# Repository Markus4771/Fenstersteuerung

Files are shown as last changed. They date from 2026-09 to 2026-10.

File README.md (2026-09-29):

# Fenstersteuerung

Modulare ESP32-S3-basierte Fenster-/Rollladensteuerung mit 230-V-Rollladenansteuerung, Reedkontakten, RS485 und zwei ULN2003-Ausgangsgruppen.

## Aktueller Hauptplatinenstand

**v3.3ebs2**

Datei:

`hardware/Hauptplatine/Hauptplatine_v3.3ebs2_library_clean_usb_clearance_150x90.kicad_pcb`

### DRC-Status

Der aktuelle KiCad-DRC ist elektrisch sauber:

- 0 offene Verbindungen
- 0 Kurzschlüsse
- 0 Leiterbahnkreuzungen
- 0 Clearance-Fehler
- 0 Dangling-Tracks
- 0 Silkscreen-Warnungen
- 0 Footprint-Fehler

Es verbleiben nur 30 Bibliothekswarnungen durch angepasste bzw. lokal fehlende Footprint-Bibliotheken.

## Hauptfunktionen

- ESP32-S3 DevKitC-1
- 2 × Finder 40.52, 5-V-Spule, DPDT
- Hardware-Interlock für Rollladen AUF/AB
- Mean Well IRM-20-5
- AMS1117-3.3 mit 22-µF-Ausgangskondensator
- MAX3485 RS485
- 2 × ULN2003A
- 2 × 28BYJ-48-Ausgangsgruppe
- Reedkontakte für Offen/Gekippt
- 230-V-Motoranschluss
- getrennte 230-V- und SELV-Bereiche

## Wichtige Dateien

- PCB: `hardware/Hauptplatine/Hauptplatine_v3.3ebs2_library_clean_usb_clearance_150x90.kicad_pcb`
- DRC-Regeln: `hardware/Hauptplatine/Hauptplatine.kicad_dru`
- 230-V-Prüfung: `hardware/Hauptplatine/230V-SICHERHEITSPRUEFUNG.md`
- BOM: `bom/Hauptplatine_v3.3ebs2_BOM.csv`
- Entwicklungsarchiv: `hardware/Hauptplatine/archive/`
- Historie: `docs/ENTWICKLUNGSHISTORIE.md`
- Übergabe für neuen Chat: `NEUER-CHAT.md`

## Noch vor der Prototypenbestellung

1. BOM gegen tatsächlich bestellte Bauteile prüfen.
2. Gerber- und Drill-Dateien aus KiCad erzeugen.
3. Gerber im Viewer kontrollieren.
4. 230-V-Sicherheitsprüfung final abschließen.
5. Erste Inbetriebnahme zunächst ohne Netzspannung durchführen.

## Sicherheit

Der saubere KiCad-DRC ist keine formale Freigabe für 230-V-Betrieb. Luft-/Kriechstrecken, PE-Führung, Absicherung, Bauteilzulassungen, Gehäuse und Endanwendung müssen separat geprüft werden.

## Update v3.3ebs2

- elektrisch sauberer v3.3ebq2-Stand übernommen
- RS485-Klemme bleibt unten, USB-C frei zugänglich
- alle 17 verwendeten Footprints auf projektlokale Bibliothek `Fenstersteuerung.pretty` umgestellt
- `fp-lib-table` liegt im Hauptplatinen-Ordner
- gegenüber v3.3ebq2 keine Änderungen an Routing, Pads, Vias oder Kupfer
- nächster Schritt: KiCad öffnen, Zonen neu füllen und DRC ausführen

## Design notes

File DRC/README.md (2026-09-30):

# DRC-Berichte

Hier werden die KiCad-Design-Rule-Check-Berichte der jeweiligen Hauptplatinen- und Sensorplatinen-Versionen abgelegt.

Ein sauberer DRC ersetzt nicht die zusätzliche Prüfung der tatsächlichen Netzkonnektivität und der 230-V-Sicherheitsabstände.

## Hauptplatine v3.3ebs2

Aktive PCB-Datei:

`hardware/Hauptplatine/Hauptplatine_v3.3ebs2_library_clean_fixed_150x90.kicad_pcb`

Ergebnis der zuletzt vom Benutzer in KiCad ausgeführten DRC-Läufe:

- 0 unverbundene Pads
- 0 Footprint-Fehler
- keine elektrischen Clearance-Fehler
- keine gemeldeten Verstöße gegen die projektspezifischen 230-V-Regeln
- 30 Warnungen vom Typ `lib_footprint_mismatch`

### Bewertung der 30 Library-Mismatch-Warnungen

Die projektlokale Bibliothek `Fenstersteuerung.pretty` wird von KiCad korrekt gefunden.

Ein exemplarischer Direktvergleich des Sicherungshalters
`Fenstersteuerung:Littelfuse_646_5x20`
mit dem auf der PCB eingebetteten Footprint zeigt:

- gleicher Padabstand: 22,7 mm
- gleiche Padgröße: 2,4 x 2,4 mm
- gleicher Bohrdurchmesser: 1,4 mm
- gleicher Gehäuseumriss
- keine Abweichung der für die Fertigung relevanten Grundgeometrie festgestellt

Die verbleibende Warnung ist daher nach aktuellem Prüfstand als Bibliotheks-/Metadatenabweichung zu behandeln und nicht als elektrischer DRC-Fehler.

Vor Fertigungsfreigabe bleiben dennoch erforderlich:

1. Gerber- und Drill-Daten erzeugen.
2. Gerber visuell gegen die PCB prüfen.
3. reale Kaufteile gegen die Footprints prüfen.
4. 230-V-Sicherheitsprüfung separat abschließen.

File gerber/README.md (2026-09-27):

# Gerber

Fertigungsdaten werden erst abgelegt, wenn Routing, DRC, Konnektivitätsprüfung und die separate Sicherheitsprüfung des 230-V-Bereichs abgeschlossen sind.

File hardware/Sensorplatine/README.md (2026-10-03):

# Sensorplatine

## Status

Aktueller Entwicklungsstand: **v4.0.ac**. Diese Version ist der aktuelle manuell platzierte KiCad-10-Basisstand ohne Leiterbahnen und Vias.

Die Sensorplatine ist als abgesetzte Raumklima- und Anwesenheitssensorplatine für die Fenstersteuerung vorgesehen. Die Reedkontakte für Fenster offen/gekippt bleiben direkt an der Hauptplatine und gehören ausdrücklich **nicht** auf diese Sensorplatine.

## Geplante Messgrößen und Bausteine

| Messgröße | Vorgesehener Baustein | Schnittstelle | Hinweis |
|---|---|---|---|
| Temperatur | BME280 | I²C | gemeinsamer Sensor mit Feuchte und Luftdruck |
| Luftfeuchtigkeit | BME280 | I²C | ±3 % rF typischer Einsatzbereich laut Hersteller |
| Luftdruck | BME280 | I²C | 300…1100 hPa |
| CO₂ | Sensirion SCD41 | I²C | echter CO₂-Sensor, spezifizierter Bereich 400…5000 ppm |
| VOC / Luftqualität | Sensirion SGP40 | I²C | VOC-Index für Lüftungs-/Luftgütelogik |
| Helligkeit | Vishay VEML7700 | I²C | digitaler Umgebungslichtsensor |
| Bewegung / Anwesenheit | modular | GPIO / UART | PIR oder mmWave-Modul; endgültiger Typ noch festzulegen |
| Schallpegel | digitales MEMS-Mikrofon | I²S | z. B. INMP441-Klasse; relative Geräuschpegelmessung, keine normgerechte Schallpegelmessung |

## Architektur

Ziel ist, möglichst viele Sensoren über **I²C** anzubinden. Dadurch benötigen BME280, SCD41, SGP40 und VEML7700 gemeinsam nur SDA und SCL.

Zusätzlich werden benötigt:

- I²S-Leitungen für das digitale MEMS-Mikrofon
- mindestens ein GPIO für einen PIR-Sensor
- optional UART für ein mmWave-Anwesenheitsmodul
- Versorgung 3,3 V und ggf. 5 V
- GND

## Bewegung / Anwesenheit

Die Platine soll so vorbereitet werden, dass entweder:

1. ein einfacher PIR-Bewegungssensor verwendet werden kann, oder
2. ein mmWave-Anwesenheitssensor über einen Steckverbinder angeschlossen werden kann.

mmWave ist besonders interessant, weil damit auch ruhende Personen erkannt werden können. Wegen Baugröße und unterschiedlicher Modulvarianten soll der mmWave-Sensor zunächst nicht fest als SMD-Bauteil auf die Platine gesetzt werden.

## Schallpegel

Die Schallmessung soll mit einem digitalen MEMS-Mikrofon erfolgen.

Ziel:

- relativer Geräuschpegel
- Erkennung von ungewöhnlich hoher Lautstärke
- Verlauf über die Zeit
- mögliche spätere Nutzung für Anwesenheits-/Komfortlogik

Die Platine ist **nicht** als kalibriertes oder normgerechtes Schallpegelmessgerät vorgesehen.

## Mechanik / Layout

Beim späteren PCB-Layout beachten:

- BME280 möglichst weit von Spannungsreglern, ESP32 und anderen Wärmequellen platzieren
- SCD41 mit freiem Luftaustausch montieren
- SGP40 ebenfalls mit gutem Luftaustausch platzieren
- VEML7700 an einer Gehäuseöffnung bzw. lichtdurchlässigen Stelle platzieren
- Mikrofon mit definierter Schallöffnung im Gehäuse
- Sensorbereiche nicht unnötig durch Kupferflächen oder Wärmequellen aufheizen
- Befestigungsbohrungen vorsehen
- Beschriftung der Steckverbinder auf dem Silkscreen

## Noch festzulegen

1. Verbindung zwischen Hauptplatine und Sensorplatine
2. Kabellänge zwischen beiden Platinen
3. Versorgungsspannung(en) der Sensorplatine
4. PIR- und/oder mmWave-Modultyp
5. endgültiger MEMS-Mikrofontyp
6. Gehäuseabmessungen und Position der Luft-/Licht-/Schallöffnungen
7. Schutzbeschaltung für die Verbindung zur Hauptplatine
8. KiCad-Schaltplan und PCB-Version v1.0

## Schaltplanstand v1.0

Aktiver Entwurf:

- `Sensorplatine_v1.0.sch`
- lokale Symbolbibliothek: `Sensorplatine_v1.0-cache.lib`
- Pinbelegung: `PINBELEGUNG_v1.0.csv`
- Schaltplan-Spezifikation: `SCHALTPLAN_v1.0.md`

Der Schaltplan enthält bereits:

- STM32G031K8T6 (LQFP-32)
- AP2112K-3.3
- MAX3485 / RS485
- BME280
- SCD41
- SGP40
- VEML7700
- HLK-LD2450
- I2S-MEMS-Mikrofon als noch zu finalisierender Typ
- 4-poligen Anschluss zur Hauptplatine
- SWD-Programmieranschluss

### Vor PCB-Layout noch final festzulegen

1. konkreter I2S-MEMS-Mikrofontyp und Footprint
2. RS485-TVS-Typ
3. 120-Ohm-Abschluss als Jumper/Lötbrücke
4. endgültiger 4-poliger Steckverbinder
5. Footprint des HLK-LD2450 und Antennen-Keepout
6. mechanische Positionen innerhalb 50 x 50 mm

## PCB-Placement v1.0

Erster mechanischer 50 x 50 mm Placement-Entwurf:

`Sensorplatine_v1.0_placement_50x50.kicad_pcb`

Aktuelle Platzierung:

- HLK-LD2450 entlang der oberen Platinenkante
- definierter Antennen-Keepout an der Oberkante
- SCD41 links mit eigener Luftzone
- BME280 und SGP40 mittig im Sensorbereich
- VEML7700 am rechten Rand
- STM32G031K8T6 zentral unten
- MAX3485 und SM712 nahe RS485-Seite
- AP2112K-3.3 unten rechts
- T5848 nahe Gehäuserand für Schallöffnung
- JST-XH 4-polig unten links
- SWD-Header unten
- zunächst zwei 2.5-mm-Befestigungsbohrungen unten

Dieser Stand ist absichtlich noch nicht geroutet. Vor dem Routing werden Footprints und mechanische Abstände final geprüft.

## Routing-Stand v1.0

Neue Datei:

`Sensorplatine_v1.0_routing_draft_50x50.kicad_pcb`

Bereits elektrisch geroutet:

- 5-V-Eingang vom JST-XH-Stecker zum AP2112K
- 3,3-V-Versorgung vom AP2112K zum STM32 und MAX3485
- GND-Verbindungen im Kernbereich
- RS485 A/B vom Hauptanschluss über SM712 zum MAX3485
- USART-Verbindungen MAX3485 <-> STM32
- DE/RE-Steuerung MAX3485 <-> STM32

Die Sensor-Footprints sind in diesem Stand noch bewusst als Platzhalter markiert. Vor dem Routing von I2C, I2S und LD2450 werden die exakten Hersteller-Landpatterns übernommen und geprüft.

## Maximaler Routing-Stand – v1.0

In `Sensorplatine_v1.0_routing_draft_50x50.kicad_pcb` sind jetzt zusätzlich geroutet:

- I2C SDA/SCL vom STM32 bis in die zentrale Sensorzone
- UART TX/RX vom STM32 bis zur LD2450-Modulschnittstelle
- 5 V und GND bis zur LD2450-Modulschnittstelle
- I2S WS / CK / SD vom STM32 bis zur Mikrofonzone
- SWDIO / SWCLK / NRST / 3V3 / GND bis zum SWD-Header

Damit sind praktisch alle langen bzw. kritischen Leiterbahnstrecken vorgeroutet.

Noch offen bleiben nur die kurzen lokalen Verbindungen direkt an:

- BME280
- SCD41
- SGP40
- VEML7700
- T5848
- endgültiges LD2450-Landpattern

Grund: Für diese Bauteile werden vor einer fertigungstauglichen Version die exakten Hersteller-Landpatterns übernommen. Die derzeitigen Sensorflächen sind ausdrücklich noch Platzhalter.

Der aktuelle Stand ist daher ein **maximal gerouteter mechanisch-elektrischer Entwurf**, aber noch keine freigegebene Fertigungsdatei. Vor Gerber-Erzeugung müssen die finalen Footprints eingesetzt und ein KiCad-DRC durchgeführt werden.

## Versionierung

Ab jetzt wird die Sensorplatine strikt versionsbasiert weiterentwickelt.

Regeln:

- vorhandene Hardwareversionen werden nicht mehr überschrieben
- jede elektrische oder mechanische Änderung erzeugt eine neue Version
- reine Dokumentationskorrekturen können innerhalb derselben Version dokumentiert werden
- DRC-Berichte werden passend zur jeweiligen Version abgelegt
- Gerber-Dateien erhalten immer dieselbe Versionsnummer wie das zugehörige PCB

Aktueller Stand:

- **v1.0** = erster 50 x 50 mm Sensorplatinen-Entwurf mit STM32G031, RS485, LD2450 und vorgerouteten Sensorbussen
- nächste Entwicklungsstufe: **v1.1**

Geplante Dateinamen:

- `Sensorplatine_v1.0_routing_draft_50x50.kicad_pcb` – eingefrorener aktueller Stand
- `Sensorplatine_v1.1_50x50.kicad_pcb` – nächste bearbeitete PCB-Version
- `DRC_v1.0.rpt`, `DRC_v1.1.rpt` usw.
- spätere Gerber: `Sensorplatine_v1.1_Gerber.zip` usw.

## Version v1.2

Datei:

`Sensorplatine_v1.2_50x50.kicad_pcb`

Änderungen gegenüber v1.1:

- 5-V-Versorgung neu geroutet
- GND-Backbone neu aufgebaut
- 3,3-V-Verteilung neu geroutet
- RS485 A/B getrennt geführt
- MAX3485 <-> STM32 neu geroutet
- I2C bis zur Sensorzone geroutet
- LD2450 UART sowie 5 V/GND bis zur Modulschnittstelle geroutet
- I2S bis zur Mikrofonzone geroutet
- SWD neu geroutet
- SWD-Header weiter in die Platinenkontur verschoben

Hinweis:
v1.2 basiert auf der in GitHub gespeicherten v1.1. Lokal in KiCad verschobene Bauteile aus einer nicht hochgeladenen `.kicad_pcb` konnten noch nicht übernommen werden.

## Version 4.0

### v4.0.aa – manuelle Neuplatzierung

Datei:

`Sensorplatine_v4.0.aa_placement_only_50x50.kicad_pcb`

- neue manuelle Bauteilplatzierung
- KiCad-10-Dateiformat
- keine Leiterbahnen
- keine Vias
- dient als saubere mechanische Ausgangsbasis

### v4.0.ab – Routingversuch

Datei:

`Sensorplatine_v4.0.ab_50x50.kicad_pcb`

DRC:

`DRC_v4.0.ab.rpt`

Dieser Stand war ein maximaler 2-Lagen-Routingversuch. Der DRC zeigte zu viele geometrische Konflikte und Kurzschlüsse. **v4.0.ab ist deshalb ausdrücklich nicht für Fertigung oder weitere Entwicklung freigegeben.**

### v4.0.ac – aktueller Basisstand

Datei:

`Sensorplatine_v4.0.ac_50x50.kicad_pcb`

- basiert auf der aktuellen manuellen Bauteilplatzierung
- KiCad 10
- aktuell 0 Leiterbahnsegmente
- aktuell 0 Vias
- neuer Ausgangspunkt für das nächste kontrollierte Routing
- Bauteilpositionen sollen vor dem nächsten Routing nicht automatisch verändert werden

**Aktueller Arbeitsstand: v4.0.ae**

### v4.0.ad – konservatives Kernrouting

Datei:

`Sensorplatine_v4.0.ad_50x50.kicad_pcb`

- basiert auf v4.0.ac
- manuelle Bauteilplatzierung unverändert
- +5 V und GND im Kernbereich geroutet
- RS485_A und RS485_B geroutet
- D1 und U7 im RS485-Pfad berücksichtigt
- +3V3 von U9 zu U7 geroutet
- enge Sensor-, I2C-, I2S- und SWD-Bereiche noch bewusst offen
- vor Weiterentwicklung ist ein neuer KiCad-DRC erforderlich

**Aktueller Arbeitsstand: v4.0.ad**

### v4.0.ae – RS485-only routing

Datei:

`Sensorplatine_v4.0.ae_50x50.kicad_pcb`

- basiert auf der reinen v4.0.aa-Manuellplatzierung
- nur RS485_A und RS485_B geroutet
- D1 und U7 angebunden
- Versorgung, I2C, I2S und SWD bleiben bewusst offen
- Ziel: zuerst einen DRC-sauberen RS485-Kern herstellen

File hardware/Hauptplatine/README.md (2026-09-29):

# Hauptplatine – KiCad-Projektordner

## Wichtig beim Öffnen

Nicht nur die einzelne `.kicad_pcb`-Datei herunterladen.

Für die projektlokale Footprint-Bibliothek müssen diese Dateien/Ordner zusammen bleiben:

- `Hauptplatine_v3.3ebs2_library_clean_fixed_150x90.kicad_pcb`
- `fp-lib-table`
- `Fenstersteuerung.pretty/`
- `Hauptplatine.kicad_dru`

Am einfachsten:

1. komplettes Repository herunterladen/klonen
2. in `hardware/Hauptplatine/` wechseln
3. `Hauptplatine_v3.3ebs2_library_clean_fixed_150x90.kicad_pcb` aus diesem Ordner öffnen

Die `fp-lib-table` verweist auf:

`${KIPRJMOD}/Fenstersteuerung.pretty`

Wenn nur die PCB-Datei separat heruntergeladen wird, kann KiCad die lokale Bibliothek nicht finden und meldet für alle Footprints:

`Die aktuelle Konfiguration enthält die Footprint-Bibliothek "Fenstersteuerung" nicht`

## Aktueller DRC-Stand

DRCebs.rpt vom 2026-09-29:

- 0 unconnected pads
- 0 Footprint errors
- keine elektrischen DRC-Fehler
- 30 reine Library-Warnungen wegen nicht geladener Projektbibliothek

Nach Öffnen aus dem vollständigen Projektordner bitte Zonen neu füllen und DRC erneut ausführen.

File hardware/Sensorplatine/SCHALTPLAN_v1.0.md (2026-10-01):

# Sensorplatine v1.0 – Schaltplan-Spezifikation

## Ziel

50 × 50 mm Sensorplatine für die Fenstersteuerung mit eigenem STM32G031K8T6 und RS485-Anbindung an die Hauptplatine.

Die Reedkontakte bleiben an der Hauptplatine.

## Funktionsblöcke

### 1. Versorgung

Eingang von der Hauptplatine:

- +5V
- GND
- RS485_A
- RS485_B

Versorgung:

- +5V direkt für HLK-LD2450
- +5V auf 3V3 über Regler
- 3V3 für STM32G031K8T6, BME280, SCD41, SGP40, VEML7700, MAX3485 und digitales MEMS-Mikrofon

Vorgesehener Regler:

- AP2112K-3.3, SOT-23-5, 600 mA

Abblockung:

- 10 µF am 5-V-Eingang
- 10 µF am 3V3-Ausgang des Reglers
- 100 nF direkt an jedem IC
- zusätzlich 4.7 µF nahe SCD41 / SGP40

### 2. STM32

U1: STM32G031K8T6

Gehäuse:

- LQFP-32
- 7 × 7 mm
- gut handlötbar

Versorgung:

- VDD/VDDA -> 3V3
- VSS/VSSA -> GND
- 100 nF + 1 µF nahe U1

Reset:

- PF2/NRST
- 10 kΩ Pull-up nach 3V3
- Test-/Programmierzugang über SWD

SWD:

- 3V3
- GND
- SWDIO
- SWCLK
- NRST

### 3. I2C-Sensorbus

Bus:

- PB8 = I2C1_SCL
- PB9 = I2C1_SDA

Pull-ups:

- 4.7 kΩ nach 3V3 auf SDA und SCL

Teilnehmer:

#### U2 – BME280

Messgrößen:

- Temperatur
- Luftfeuchtigkeit
- Luftdruck

Anbindung:

- I2C
- VDD = 3V3
- VDDIO = 3V3
- CSB = 3V3
- SDO = GND für Standard-I2C-Adresse
- 100 nF nahe Sensor

#### U3 – SCD41

Messgröße:

- CO2

Anbindung:

- I2C
- Versorgung 3V3
- lokale Abblockung 100 nF + 4.7 µF

Mechanik:

- freie Luftzufuhr vorsehen
- nicht direkt an Wärmequellen platzieren

#### U4 – SGP40

Messgröße:

- VOC / Luftgüte

Anbindung:

- I2C
- VDD und VDDH gemeinsam an 3V3
- VSS und Center-Pad an GND
- 100 nF + lokale Pufferung

#### U5 – VEML7700

Messgröße:

- Umgebungshelligkeit

Anbindung:

- I2C
- VDD = 3V3
- GND = GND
- 100 nF nahe Sensor

Mechanik:

- am Platinenrand / Gehäusefenster platzieren

### 4. mmWave-Anwesenheit

U6/M1: HLK-LD2450

Versorgung:

- 5V direkt
- GND

UART:

- PA2 = USART2_TX -> RX des LD2450
- PA3 = USART2_RX <- TX des LD2450

Mechanik:

- Modul direkt auf Sensorplatine
- Antennenbereich an Platinenkante
- Keepout vor Antenne
- keine Kupferfläche oder große Bauteile vor der Antenne

### 5. RS485 zur Hauptplatine

U7: MAX3485, SOIC-8

Versorgung:

- VCC = 3V3
- GND = GND
- 100 nF direkt an VCC

UART:

- PB6 = USART1_TX -> DI
- PB7 = USART1_RX <- RO
- PB1 = RS485_DE

Enable:

- DE und /RE gemeinsam an PB1
- 10 kΩ Pull-down auf PB1, damit der Treiber beim Reset deaktiviert bleibt

Bus:

- A -> RS485_A
- B -> RS485_B

Abschluss:

- 120 Ω zwischen A und B
- per 2-poligem Jumper oder Lötbrücke zuschaltbar

Schutz:

- TVS für RS485 A/B vorsehen
- optional Serienwiderstände / Common-Mode-Choke als Bestückungsoption

### 6. Digitales Mikrofon

U8: TDK InvenSense T5848, digitales I2S-MEMS-Mikrofon.

Ziel:

- relativer Schallpegel
- keine normgerechte dB-Messung

I2S:

- PA4 = WS/LRCLK
- PA5 = CK/BCLK
- PA7 = SD

Versorgung:

- 3V3
- GND
- 100 nF nahe Mikrofon

Mechanik:

- Mikrofon an Platinenrand
- definierte Schallöffnung im Gehäuse

### 7. Hauptanschluss

J1: 4-poliger Anschluss Hauptplatine <-> Sensorplatine

1. +5V
2. GND
3. RS485_A
4. RS485_B

Steckertyp wird erst mit Gehäuse und Kabelwahl final festgelegt.

## STM32-Pinplanung

| Pinname | phys. Pin | Funktion |
|---|---:|---|
| PB9 | 1 | I2C SDA |
| PB8 | 28 | I2C SCL |
| PA2 | 9 | LD2450 TX |
| PA3 | 10 | LD2450 RX |
| PA4 | 11 | I2S WS |
| PA5 | 12 | I2S CK |
| PA7 | 14 | I2S SD |
| PB1 | 16 | RS485 DE + /RE |
| PB6 | 32 | RS485 TX |
| PB7 | 27 | RS485 RX |
| PA13 | 24 | SWDIO |
| PA14 | 25 | SWCLK |
| PF2/NRST | 6 | Reset |

Die physikalischen Pin-Nummern wurden gegen das aktuelle ST-Datenblatt für STM32G031KxT im LQFP-32 geprüft. Die Alternate-Functions für USART1, USART2 und I2S1 sind ebenfalls abgeglichen.

## Layoutvorgaben 50 × 50 mm

- LD2450 entlang einer Außenkante
- SCD41 und BME280 möglichst weit weg von Regler, STM32 und LD2450-Wärmequellen
- VEML7700 an einer lichtzugänglichen Außenkante
- MEMS-Mikrofon an einer Gehäuseöffnung
- RS485- und 5-V-Anschluss an einer gemeinsamen Kabelseite
- 4 Befestigungsbohrungen, soweit der verfügbare Raum dies zulässt
- GND-Fläche, aber Antennen-Keepout des LD2450 beachten
- Testpunkte für 5V, 3V3, GND, SDA, SCL, RS485_A, RS485_B, TX/RX

## Noch offen

1. endgültiger Footprint des HLK-LD2450
2. Gehäuse und Öffnungen
3. mechanische Platzierung auf 50 x 50 mm
4. PCB-Routing und DRC

## Festgelegte Bauteile – Update

### U8 – TDK InvenSense T5848
- digitaler I2S-Ausgang
- Bottom-Port-MEMS-Mikrofon
- ca. 3.50 x 2.65 x 0.98 mm
- Status: Production
- benötigt eine Schallöffnung im PCB/Gehäuse
- Hinweis: wegen Bottom-Pads nicht klassisch mit Lötkolben an allen Anschlüssen zugänglich; Reflow/Heißluft empfohlen

### D_RS485 – Littelfuse SM712
- speziell für RS485/RS422-Schutz
- asymmetrische TVS-Auslegung für Busleitungen
- zwischen RS485 A/B und GND gemäß Hersteller-Applikation platzieren
- möglichst nahe am externen Steckverbinder

### J1 – JST XH, 4-polig, 2.50 mm
- Through-Hole-Ausführung
- gut von Hand lötbar
- 3 A bei AWG22 laut JST
- Pinbelegung:
  1. +5V
  2. GND
  3. RS485_A
  4. RS485_B

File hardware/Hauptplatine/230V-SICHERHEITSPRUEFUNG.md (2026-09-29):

# 230-V-Sicherheitsprüfung Hauptplatine

Stand: v3.3ebs2  
Status: Entwicklungs-/Prototypenprüfung, **keine formale Sicherheits- oder Fertigungsfreigabe**

## Aktueller Prüfstand

Aktive PCB-Datei:

`hardware/Hauptplatine/Hauptplatine_v3.3ebs2_library_clean_fixed_150x90.kicad_pcb`

Verwendete Designregeln:

`hardware/Hauptplatine/Hauptplatine.kicad_dru`

Interne Entwicklungsziele:

- mindestens 1,5 mm zwischen unterschiedlichen Netzspannungs-Potentialen
- mindestens 6 mm zwischen Netzspannung und SELV
- mindestens 2,0 mm Leiterbahnbreite für Netzspannungsnetze

## Statisch verifizierte Punkte v3.3ebs2

### Netzspannungs-Leiterbahnbreite

Aus der PCB-Datei wurden 56 Leiterbahnsegmente der folgenden Netze ausgewertet:

- AC_L
- AC_N
- PE
- L_PSU_FUSED
- L_MOTOR
- UP_FEED
- DN_FEED
- MOTOR_UP
- MOTOR_DN

Ergebnis:

- kleinste gefundene Leiterbahnbreite: **2,0 mm**
- Segmente unter 2,0 mm: **0**

Damit wird das interne Entwicklungsziel für die Leiterbahnbreite in der statisch ausgewerteten PCB-Geometrie eingehalten.

### Trennung Netzspannung / SELV

Die Leiterplatte besitzt eine echte Kupfer-Keepout-Zone auf F.Cu und B.Cu:

- x = 71 .. 77 mm
- Breite = **6 mm**
- Tracks verboten
- Vias verboten
- Copper Pour verboten

Statische Auswertung der 56 Netzspannungs-Leiterbahnsegmente:

- Netzspannungs-Tracks, die die Keepout-Zone durchqueren: **0**

### Komponenten-/Footprint-Stand

Folgende zuvor problematische Footprints wurden im aktuellen Stand korrigiert bzw. auf die projektlokale Bibliothek umgestellt:

- Mean Well IRM-20-5
- Finder 40.52
- Littelfuse 646 Sicherungshalter
- ESP32-S3 DevKitC-1 Carrier
- Phoenix MKDS Klemmen
- MOV S14K275
- weitere Standard-Footprints in `Fenstersteuerung.pretty`

## Bereits umgesetzte Schutzmaßnahmen

- 6-mm-Trennzone zwischen 230-V-/Motorbereich und SELV-/Logikbereich
- 2,0-mm-Netzspannungsleiterbahnen
- getrennte Sicherung für Netzteilzweig und Motorzweig
- MOV auf der Netzseite
- galvanisch getrenntes AC/DC-Netzteil
- Relaiskontakte räumlich von den Spulenanschlüssen getrennt
- PE wird als eigenes Netz von J1 zum Motorausgang J5 geführt

## Noch vor Prototypenbestellung erforderlich

1. PCB in KiCad 10 öffnen.
2. Alle Kupferzonen neu füllen.
3. `Hauptplatine.kicad_dru` im Design Rule Editor laden bzw. prüfen.
4. „Check rule syntax“ ausführen.
5. vollständigen KiCad-DRC ausführen.
6. insbesondere alle MAINS-different-net-clearance-Verstöße prüfen.
7. bestätigen, dass zwischen allen unterschiedlichen 230-V-Potentialen mindestens das interne Ziel von 1,5 mm erreicht wird.
8. tatsächliche Kaufteile gegen Footprints prüfen:
   - Littelfuse 646
   - Finder 40.52.9.005.0000
   - Mean Well IRM-20-5
   - Phoenix-Klemmen
   - MOV
9. Gerber- und Drill-Daten visuell prüfen.
10. Erstinbetriebnahme ohne Netzspannung durchführen.
11. Netzspannung erst nach separater elektrischer Sicherheitskontrolle anlegen.

## Normative Einordnung

Die oben verwendeten Abstände sind konservative interne Entwicklungsziele und stellen **keinen Nachweis einer Normkonformität** dar.

Die tatsächlich erforderlichen Luft- und Kriechstrecken hängen unter anderem ab von:

- anzuwendender Produktnorm
- Überspannungskategorie
- Verschmutzungsgrad
- Leiterplatten-Materialgruppe / CTI
- Einsatzhöhe
- Basisisolation oder verstärkter Isolation
- Gehäuse und Berührschutz
- Absicherung und Fehlerfallbetrachtung

Vor einem produktiven Einsatz an 230 V ist deshalb eine separate fachliche Sicherheitsbewertung erforderlich.

## Ergebnis v3.3ebs2

Der aktuelle PCB-Stand ist gegenüber den früheren Revisionen wesentlich bereinigt:

- keine Netzspannungsleiterbahn unter 2,0 mm
- keine Netzspannungsleiterbahn durchquert die 6-mm-SELV-Keepout-Zone
- Routing ist vollständig
- Footprints wurden auf die projektlokale Bibliothek vereinheitlicht

Die **finale Freigabe hängt jetzt vor allem vom vollständigen KiCad-DRC mit den Hochspannungsregeln sowie der Prüfung der realen Kaufteile ab**.

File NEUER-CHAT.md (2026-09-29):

# NEUER-CHAT – Fenstersteuerung

## Repository

`Markus4771/Fenstersteuerung`

## Aktueller Stand

Aktuelle Hauptplatine:

`hardware/Hauptplatine/Hauptplatine_v3.3ebs2_library_clean_usb_clearance_150x90.kicad_pcb`

Status:

- Routing abgeschlossen
- 0 offene Verbindungen
- 0 Kurzschlüsse
- 0 Track-Kreuzungen
- 0 Clearance-Fehler
- 0 Dangling-Tracks
- 0 Silkscreen-Warnungen
- nur noch 30 nicht-elektrische Library-Warnungen

## Wichtige Korrekturen des finalen Standes

- Mean Well IRM-20-5 Footprint und Pinbelegung korrigiert
- Finder 40.52 auf offizielles Pinraster korrigiert
- Littelfuse-646-Sicherungshalter auf 22,7-mm-Raster korrigiert
- AMS1117 mit 22-µF-Ausgangskondensator ergänzt
- ESP32-S3 DevKitC-1 J1-Pinbelegung korrigiert
- 230-V-Abstände verbessert
- GND-Zoneninseln und Silkscreen-Warnungen bereinigt

## Projektstruktur

- `hardware/Hauptplatine/` – aktiver Hauptplatinenstand
- `hardware/Hauptplatine/archive/` – alte PCB-Zwischenstände
- `bom/` – Stückliste
- `gerber/` – spätere Fertigungsdaten
- `docs/ENTWICKLUNGSHISTORIE.md` – ausführliche Entwicklungshistorie
- `DRC/` – DRC-Dokumentation

## Nächste Schritte

1. BOM gegen reale Bauteile prüfen.
2. Gerber und Drill in KiCad erzeugen.
3. Gerber visuell prüfen.
4. 230-V-Sicherheitsprüfung finalisieren.
5. Prototyp bestellen.
6. Erstinbetriebnahme ohne Netzspannung.
7. Danach 5 V / 3,3 V / ESP32 / RS485 / Relais / Stepper prüfen.
8. Netzspannung erst nach separater Sicherheitsprüfung.

## Hinweis

Nicht mit Dateien aus `hardware/Hauptplatine/archive/` weiterarbeiten. Aktive Basis ist ausschließlich **v3.3ebs2**.

## Update v3.3ebs2

- elektrisch sauberer v3.3ebq2-Stand übernommen
- RS485-Klemme bleibt unten, USB-C frei zugänglich
- alle 17 verwendeten Footprints auf projektlokale Bibliothek `Fenstersteuerung.pretty` umgestellt
- `fp-lib-table` liegt im Hauptplatinen-Ordner
- gegenüber v3.3ebq2 keine Änderungen an Routing, Pads, Vias oder Kupfer
- nächster Schritt: KiCad öffnen, Zonen neu füllen und DRC ausführen

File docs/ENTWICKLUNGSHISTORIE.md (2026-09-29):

# Entwicklungshistorie – Fenstersteuerung

Diese Datei enthält die frühere ausführliche Entwicklungsdokumentation aus `NEUER-CHAT.md`.

> Hinweis: Für den aktuellen Projektstand bitte `README.md` und `NEUER-CHAT.md` im Repository-Stamm verwenden.

---

# NEUER-CHAT – Fenstersteuerung

## Projekt

GitHub:
https://github.com/Markus4771/Fenstersteuerung

## Ziel

Kompakte ESP32-basierte Fenster-/Rollladensteuerung.

Die Hauptelektronik sitzt im Rollladenkasten. Die Sensorik wird abgesetzt. Das System soll bewusst mehr können als ein einfacher Rollladenaktor:

- Rollladen AUF/AB
- Fenster offen/gekippt erkennen
- Präsenz erkennen
- Raumklima erfassen
- Endlagen-/Hilfsmechanik ansteuern
- Sensorplatine per RS485 anbinden

Es ist **kein Fensterantrieb** vorgesehen.

## Festgelegte Hardware

### Hauptplatine

- ESP32-S3
- 2 x Finder 40.52
- 5-V-Spulen
- DPDT
- Hardware-Interlock
- 230-V-Rollladenmotor-Ausgänge
- 2 x ULN2003
- TOP/BOTTOM-Ausgangsgruppen
- 28BYJ-48 + ULN2003 für Endlagen-/Verstellmechanik
- Reed-Eingänge
- RS485
- ca. 150 x 90 mm
- 2-lagig

### Sensorplatine

- ESP32-C3
- RS485
- 4 Adern zur Hauptplatine:
  - 5 V
  - GND
  - A
  - B
- 3,3-V-kompatibler RS485-Transceiver, z. B. MAX3485
- LD2450 fest eingeplant
- SHT40
- SCD41 optional
- MQ-2 optional

### Reedkontakte

Zwei kabelgebundene Reedkontakte:

1. Fenster offen
2. Fenster gekippt

Die Reedkontakte werden per Kabel direkt von der Hauptelektronik herausgeführt.

## Stromversorgung

Festgelegt:

- 230 V AC Eingang
- Mean Well IRM-20-5
- 5 V / 4 A
- 5-V-Bus
- separate 3,3-V-Regelung
- klare Trennung zwischen Netzspannung und SELV

## Aktuelle PCB-Version

Aktuell:

**Hauptplatine_v3.3al_logic_minimal_150x90.kicad_pcb**

Repository-Pfad:

`hardware/Hauptplatine/Hauptplatine_v3.3al_logic_minimal_150x90.kicad_pcb`

Wichtig:

- v3.3h ist noch nicht vollständig geroutet
- keine Fertigungsfreigabe
- v3.3g basiert auf v3.3f; v3.3f basiert wiederum auf dem sauberen v3.3c-Stand
- v3.3d/v3.3e wegen Routing-Konflikten nicht weiterverwenden
- RS485_A/B weiterhin bewusst offen
- TOP_COIL_1–4 sind aus v3.3f übernommen
- BOT_COIL_1–4 wurden in v3.3g neu geroutet
- BOT_COIL_1 liegt bewusst auf B.Cu, BOT_COIL_2–4 auf F.Cu, um Kreuzungen zu vermeiden

## Noch offene Netze

- TOP_COIL_1–4: DRC prüfen
- BOT_COIL_1–4: neu in v3.3g, DRC prüfen
- STEP_TOP_1–4
- STEP_BOT_1–4
- ROLL_UP
- ROLL_DN
- K1_COIL_LOW
- K2_COIL_LOW
- RS485_A
- RS485_B
- REED_OPEN final prüfen
- REED_TILT final routen/prüfen
- +5 V final prüfen
- GND final prüfen

## Routing-Regel aus den bisherigen Versuchen

Nicht mehrere Netzgruppen gleichzeitig automatisch routen.

Empfohlene Reihenfolge:

1. TOP_COIL
2. BOT_COIL
3. STEP_TOP/BOT
4. Relaisansteuerung
5. RS485
6. Reed-Eingänge
7. Versorgung/GND
8. komplette physische Konnektivitätsprüfung
9. finaler DRC

## Wichtige Lektion aus DRC 3.3c

Ein DRC mit "0 unconnected pads" darf **nicht** automatisch als vollständiges Routing interpretiert werden.

Zusätzlich immer direkt in der PCB-Datei prüfen:

- ob jedes verwendete Netz Leiterbahnsegmente besitzt
- ob alle Pads tatsächlich elektrisch verbunden sind
- ob keine Ratsnest-Verbindungen offen sind

## Fertigungsfreigabe

Nur wenn:

- alle verwendeten Pads physisch verbunden sind
- keine Kurzschlüsse vorhanden sind
- keine Leiterbahnkreuzungen vorhanden sind
- keine offenen/dangling Tracks vorhanden sind
- DRC sauber ist
- RS485 korrekt geroutet ist
- Netzspannungsbereich separat sicherheitstechnisch geprüft ist
- Gerberdaten visuell geprüft sind

## 230-V-Bereich

Vor Produktion separat prüfen:

- Luftstrecken
- Kriechstrecken
- Absicherung
- Leiterbahnbreiten
- Abstand zu 5 V / 3,3 V / GND
- Relaiskontaktführung
- Motoranschlüsse
- Schutzmaßnahmen

Der 230-V-Bereich darf nicht allein aufgrund eines sauberen DRC freigegeben werden.

## Update v3.3h

DRC v3.3g:
- 63 DRC-Verstöße
- 54 offene Verbindungen
- keine gemeldeten Kurzschluss- oder Leiterbahnkreuzungs-Kategorien
- TOP/BOT-Coil-Leitungen hatten offene Enden, weil die Startpunkte nicht auf den tatsächlichen U4/U5-Pads lagen

v3.3h:
- alle bisherigen TOP_COIL_1–4- und BOT_COIL_1–4-Tracks entfernt
- acht Coil-Netze neu direkt von U4/U5 zu J6/J7 geroutet
- tatsächliche Padkoordinaten aus dem DRC/Board verwendet
- nächster Schritt: DRC v3.3h prüfen, erst danach STEP_TOP/STEP_BOT routen

## Update v3.3i

Grund:
- DRC v3.3h zeigte erneut Pad-Kollisionen/Kreuzungen durch direkte diagonale Coil-Leitungen über U4/U5.

Änderungen:
- alle TOP_COIL_1–4- und BOT_COIL_1–4-Tracks aus v3.3h entfernt
- neue Routingstrategie: zuerst horizontal rechts aus U4/U5 herausfächern
- TOP_COIL_1/2 und BOT_COIL_1/2 auf F.Cu
- TOP_COIL_3/4 und BOT_COIL_3/4 mit gezielten Vias auf B.Cu
- keine direkte Diagonalführung mehr durch den DIP-Padbereich
- nächster Schritt: DRC v3.3i prüfen

## Update v3.3j

Wichtige Korrektur:
- Die bisherigen U4/U5-Padkoordinaten waren bei den Routingversuchen falsch transformiert.
- U4/U5 sind im PCB um 90 Grad gedreht; lokale Padkoordinaten müssen entsprechend in globale Koordinaten umgerechnet werden.
- Diese falsche Umrechnung war die Hauptursache der Coil-Padkollisionen in v3.3h/v3.3i.

v3.3j:
- alle TOP/BOT-Coil-Tracks aus der Basis entfernt
- nur TOP_COIL_1–4 neu geroutet
- korrekte globale U4-Padkoordinaten verwendet:
  - TOP1 U4.16: 139.42 / 88.12
  - TOP2 U4.15: 136.88 / 88.12
  - TOP3 U4.14: 134.34 / 88.12
  - TOP4 U4.13: 131.80 / 88.12
- korrekte globale J6-Padkoordinaten:
  - TOP1 J6.4: 164.50 / 91.00
  - TOP2 J6.3: 164.50 / 88.50
  - TOP3 J6.2: 164.50 / 86.00
  - TOP4 J6.1: 164.50 / 83.50
- alle vier TOP-Coils liegen in v3.3j auf B.Cu
- BOT_COIL bleibt bewusst offen
- nächster Schritt: DRC v3.3j prüfen

## Update v3.3k

DRC von v3.3j ausgewertet:
- 79 DRC-Verstöße
- 54 offene Verbindungen
- 3 Kurzschlussfehler
- Hauptursache: TOP-Coil-Startkoordinaten lagen fälschlich bei y=88.12 mm und liefen dadurch durch U5.

Korrektur:
- tatsächliche Koordinaten direkt aus dem KiCad-DRC übernommen
- U4-Ausgänge:
  - TOP1 U4.16: 139.42 / 72.88
  - TOP2 U4.15: 141.96 / 72.88
  - TOP3 U4.14: 144.50 / 72.88
  - TOP4 U4.13: 147.04 / 72.88
- J6:
  - TOP1 J6.4: 164.50 / 76.00
  - TOP2 J6.3: 164.50 / 78.50
  - TOP3 J6.2: 164.50 / 81.00
  - TOP4 J6.1: 164.50 / 83.50
- nur TOP_COIL_1–4 neu auf F.Cu geroutet
- BOT_COIL weiterhin offen
- nächster Schritt: DRC v3.3k

## Update v3.3l

DRC v3.3k:
- 62 DRC-Verstöße
- 47 offene Verbindungen
- TOP-Coils weiterhin fehlerhaft
- Probleme: TOP_COIL_1/3 kreuzten sich, TOP_COIL_3 kurzschloss TOP_COIL_4, mehrere Clearance- und Soldermask-Konflikte an U4

Ursache:
- Die Pinreihenfolge U4 -> J6 ist geometrisch invertiert. Vier direkte Leitungen auf einer Lage können daher nicht kreuzungsfrei geführt werden.

v3.3l:
- alle TOP/BOT-Coil-Tracks entfernt
- nur TOP_COIL_1–4 neu geroutet
- TOP1 und TOP3 auf B.Cu
- TOP2 und TOP4 auf F.Cu
- äußere und innere Routingkorridore getrennt
- keine Vias erforderlich
- BOT_COIL weiterhin offen
- nächster Schritt: DRC v3.3l

## Update v3.3m

DRC v3.3l:
- 69 DRC-Verstöße
- 50 offene Verbindungen
- 4 Kurzschlüsse
- 2 Clearance-Verstöße
- 2 dangling Tracks
- 0 Footprint-Fehler

Hauptprobleme:
- TOP_COIL_2 kollidiert mit R5/D2/Q2 und +5 V
- TOP_COIL_1 läuft in den J7/BOT-Bereich
- TOP_COIL_3 zu nah an U4-GND
- die äußeren Routingkorridore sind damit ungeeignet

v3.3m:
- alle TOP/BOT-Coil-Routen aus v3.3l entfernt
- nur TOP_COIL_1–4 neu geroutet
- je TOP-Netz zwei Vias
- erster Via direkt oberhalb der U4-Ausgangsreihe
- Hauptführung auf B.Cu außerhalb des U4-/R5-/Q2-/D2-Bereichs
- zweiter Via erst rechts neben U4, kurz vor J6
- Endstücke zu J6 auf F.Cu
- BOT_COIL bleibt bewusst offen
- nächster Schritt: DRC v3.3m

## Update v3.3n

DRC v3.3m:
- 61 DRC-Verstöße
- 47 offene Verbindungen
- nur noch 2 Kurzschlüsse bei TOP-Coils
- 1 Clearance-Verstoß
- 1 dangling Track
- 0 Footprint-Fehler

Konkrete TOP-Probleme:
- TOP_COIL_3 zu nah an Via/Track von TOP_COIL_4
- TOP_COIL_4 lief mit seiner B.Cu-Strecke zu nah an der J6-Padreihe und kurzschloss TOP_COIL_1
- zusätzlich mehrere Soldermask-Bridge-Warnungen an J6
- Via von TOP_COIL_4 lag direkt neben J6.1 und erzeugte Hole-to-hole-Warnungen

v3.3n:
- TOP_COIL_1–4 vollständig neu geroutet
- vertikale Hauptkorridore nach rechts von J6 verlegt
- J6 wird horizontal von rechts angefahren
- TOP3/TOP4-Vias weiter voneinander getrennt
- keine Vias mehr direkt an J6
- BOT_COIL weiterhin offen
- nächster Schritt: DRC v3.3n

## Update v3.3o

DRC v3.3n:
- 63 DRC-Verstöße
- 47 offene Verbindungen
- 5 Tracks-Crossing-Fehler
- 2 Kurzschlüsse
- 1 dangling Track
- 0 Footprint-Fehler

TOP-Probleme:
- TOP_COIL_1 kreuzte TOP_COIL_4
- TOP_COIL_3 kreuzte TOP_COIL_4
- TOP_COIL_2 kreuzte TOP_COIL_3 und TOP_COIL_4
- TOP_COIL_1 kreuzte TOP_COIL_2
- TOP_COIL_1 kollidierte zusätzlich mit +5 V an D2

v3.3o:
- TOP_COIL_1–4 vollständig neu geroutet
- keine Vias
- TOP1/TOP3 auf B.Cu
- TOP2/TOP4 auf F.Cu
- vier kurze Fluchtkorridore oberhalb der U4-Ausgangsreihe
- rechte Vertikalstücke bewusst gestaffelt
- Endstücke zu J6 so angeordnet, dass sie die jeweils andere Vertikalstrecke nicht schneiden
- BOT_COIL weiterhin offen
- nächster Schritt: DRC v3.3o

## Update v3.3p

DRC v3.3o:
- 54 DRC-Verstöße
- 47 offene Verbindungen
- 0 Kurzschlüsse
- 2 Tracks-Crossing-Fehler
- 1 dangling Track (REED_TILT)
- restliche Meldungen überwiegend Bibliotheks-/Silkscreen-Warnungen

Verbleibende TOP-Kreuzungen:
- TOP_COIL_2 <-> TOP_COIL_4 auf F.Cu
- TOP_COIL_1 <-> TOP_COIL_3 auf B.Cu

v3.3p:
- nur TOP_COIL_1–4 angepasst
- auf B.Cu die rechten Vertikalkorridore von TOP1/TOP3 getauscht
- auf F.Cu die rechten Vertikalkorridore von TOP2/TOP4 getauscht
- Ziel: keine Kreuzungen mehr innerhalb derselben Lage
- BOT_COIL weiterhin offen
- nächster Schritt: DRC v3.3p

## Update v3.3q

DRC v3.3p:
- 54 DRC-Verstöße
- 47 offene Verbindungen
- 0 Kurzschlüsse
- weiterhin 2 Tracks-Crossing-Fehler:
  - TOP_COIL_2 <-> TOP_COIL_4 auf F.Cu
  - TOP_COIL_1 <-> TOP_COIL_3 auf B.Cu
- 1 dangling Track bei REED_TILT
- Rest überwiegend Bibliotheks-/Silkscreen-Warnungen

Schlussfolgerung:
- Die bisherige senkrechte J6-Ausrichtung erzwingt unnötig komplizierte TOP-Routen.
- Weiteres Um-die-Pads-Routen ist nicht sinnvoll.

v3.3q:
- J6 mechanisch gedreht und nach oben versetzt
- neue J6-Position: 164.5 / 72.88, Rotation 180 Grad
- dadurch liegen TOP1..TOP4 in derselben Reihenfolge wie U4.16..U4.13
- TOP_COIL_1–4 komplett neu auf F.Cu geroutet
- vier gestaffelte horizontale Routing-Lanes
- BOT_COIL weiterhin offen
- nächster Schritt: DRC v3.3q

## Update v3.3r

DRC v3.3q:
- 72 DRC-Verstöße
- 47 offene Verbindungen
- 5 Tracks-Crossing-Fehler
- 3 Kurzschlussmeldungen
- 2 Clearance-Fehler
- 2 Hole-to-hole-Warnungen
- 1 dangling Track bei REED_TILT
- 0 Footprint-Fehler

Hauptursache:
- J6 war nach der Drehung zu dicht an U4 positioniert.
- J6.4 / TOP_COIL_1 lag praktisch auf U4.9 / +5V.
- J6.5 / +5V lag praktisch auf U4.10 / no-net.

v3.3r:
- J6 bleibt 180 Grad gedreht
- J6 von 164.5 / 72.88 auf 168.5 / 63.5 verschoben
- damit kein Pad-Overlap mit U4 mehr
- TOP_COIL_1–4 komplett neu auf B.Cu geroutet
- neue J6-Zielpunkte:
  - TOP1: 161.0 / 63.5
  - TOP2: 163.5 / 63.5
  - TOP3: 166.0 / 63.5
  - TOP4: 168.5 / 63.5
- BOT_COIL weiterhin offen
- nächster Schritt: DRC v3.3r

## Update v3.3s

DRC v3.3r:
- 73 DRC-Verstöße
- 47 offene Verbindungen
- 5 Tracks-Crossing-Fehler
- 4 Kurzschlussmeldungen
- 8 Soldermask-Bridge-Meldungen
- 1 dangling Track
- 0 Footprint-Fehler

Schlussfolgerung:
- v3.3r ist schlechter als v3.3o/v3.3p.
- Die J6-Verlegung nach oben wird verworfen.
- Bester stabiler Ausgangspunkt bleibt v3.3o: 0 Kurzschlüsse, nur 2 TOP-Kreuzungen.

v3.3s:
- Basis: v3.3o
- J6 wieder in der v3.3o-Position
- TOP1 und TOP2 bleiben auf ihren ursprünglichen Lagen
- TOP3 und TOP4 erhalten nur lokal je zwei Vias
- Layerwechsel nur an den beiden bisherigen Kreuzungsstellen
- Ziel: die zwei letzten TOP-Kreuzungen beseitigen, ohne neue lange Korridore zu erzeugen
- BOT_COIL weiterhin offen
- nächster Schritt: DRC v3.3s

## Update v3.3t

DRC v3.3s:
- 60 DRC-Verstöße
- 47 offene Verbindungen
- mehrere TOP-Kurzschlüsse
- mehrere TOP-Kreuzungen
- 1 Clearance-Fehler
- 1 dangling Track bei REED_TILT
- 0 Footprint-Fehler

Schlussfolgerung:
- Lokale Via-Hops lösen die TOP-Geometrie nicht robust.
- Stattdessen wird die Pinbelegung von J6 logisch neu geordnet.
- Bei den vier 28BYJ-Coils kann die Reihenfolge der Coil-Ausgänge frei zugeordnet und später in der Software-Schrittfolge angepasst werden.

v3.3t:
- Basis: v3.3o
- J6 bleibt mechanisch unverändert
- J6-Padbelegung geändert:
  - J6.1 = TOP_COIL_1
  - J6.2 = TOP_COIL_2
  - J6.3 = TOP_COIL_3
  - J6.4 = TOP_COIL_4
  - J6.5 = +5V unverändert
- TOP_COIL_1–4 neu als monotone, gestaffelte F.Cu-Routen geführt
- Ziel: keinerlei Kreuzungszwang mehr
- Hinweis: Schematic/Pin-Mapping muss später konsistent nachgezogen werden
- BOT_COIL bleibt weiterhin offen
- nächster Schritt: DRC v3.3t

## Update v3.3u

Ausgangslage:
- v3.3t war deutlich schlechter als v3.3o.
- bester stabiler Stand bleibt v3.3o mit 0 Kurzschlüssen und 2 TOP-Kreuzungen.

v3.3u:
- Basis: v3.3o
- J6-Pinbelegung wieder unverändert wie in v3.3o
- TOP_COIL_1–4 vollständig neu geroutet
- jede Leitung wird zuerst senkrecht aus dem U4-Padfeld herausgeführt
- erst außerhalb des Padfelds erfolgt die seitliche Führung zu J6
- TOP1/TOP3 auf B.Cu
- TOP2/TOP4 auf F.Cu
- keine Vias
- BOT_COIL weiterhin offen
- nächster Schritt: DRC v3.3u

## Update v3.3v

DRC v3.3u:
- 71 DRC-Verstöße
- 47 offene Verbindungen
- 4 Kurzschlüsse
- 1 Tracks-Crossing
- 14 Soldermask-Bridge-Meldungen
- 1 dangling Track bei REED_TILT
- 0 Footprint-Fehler

Hauptursache:
- Die neue vertikale TOP-Fluchtführung kollidierte mit der K2-Treiberzeile R5/Q2/D2.
- Besonders TOP_COIL_2 und TOP_COIL_4 trafen R5, Q2 und D2.

v3.3v:
- Basis: v3.3o
- R5/Q2/D2 von y=67 mm auf y=64 mm verschoben
- dadurch freier Routing-Korridor zwischen K2-Treiberzeile und U4
- TOP_COIL_1–4 vollständig neu geroutet
- TOP1/TOP2 auf B.Cu
- TOP3/TOP4 auf F.Cu
- keine Vias
- BOT_COIL weiterhin offen
- nächster Schritt: DRC v3.3v

## Update v3.3w

DRC v3.3v:
- 54 DRC-Verstöße
- 47 offene Verbindungen
- 0 Kurzschlüsse
- 2 Tracks-Crossing-Fehler
- 1 dangling Track bei REED_TILT
- 0 Footprint-Fehler

Verbleibende TOP-Kreuzungen:
- TOP_COIL_1 <-> TOP_COIL_2 auf B.Cu
- TOP_COIL_3 <-> TOP_COIL_4 auf F.Cu

v3.3w:
- Basis: v3.3v
- Bauteilpositionen unverändert
- nur die rechten Vertikalkorridore der TOP-Paare getauscht
- B.Cu: TOP1 innen, TOP2 außen
- F.Cu: TOP3 innen, TOP4 außen
- Ziel: die letzten zwei TOP-Kreuzungen beseitigen
- BOT_COIL weiterhin offen
- nächster Schritt: DRC v3.3w

## Update v3.3x

DRC v3.3w:
- 54 DRC-Verstöße
- 47 offene Verbindungen
- 0 Kurzschlüsse
- 2 Tracks-Crossing-Fehler
- 1 dangling Track bei REED_TILT
- 29 Bibliothekswarnungen
- 19 Silkscreen-over-Copper-Warnungen
- 2 Silkscreen-Overlap-Warnungen
- 1 Silkscreen-Edge-Warnung

Verbleibende TOP-Kreuzungen:
- TOP_COIL_1 <-> TOP_COIL_2 bei ca. x=168.2 / y=69.0
- TOP_COIL_3 <-> TOP_COIL_4 bei ca. x=166.6 / y=71.0

v3.3x:
- Basis: v3.3w
- TOP1 und TOP3 bleiben auf ihren bisherigen Lagen
- TOP2 erhält einen kurzen F.Cu-Bridge-Abschnitt nur über den TOP1-Kreuzungspunkt
- TOP4 erhält einen kurzen B.Cu-Bridge-Abschnitt nur über den TOP3-Kreuzungspunkt
- vier kleine 0.8/0.4-mm-Vias nur für diese beiden Brücken
- keine Änderungen an Bauteilpositionen
- BOT_COIL weiterhin offen
- nächster Schritt: DRC v3.3x

## Update v3.3y

DRC v3.3x:
- 52 DRC-Verstöße
- 47 offene Verbindungen
- 0 Kurzschlüsse
- 0 Tracks-Crossing-Fehler
- 1 dangling Track bei REED_TILT
- 0 Footprint-Fehler
- TOP_COIL_1–4 damit erstmals sauber geroutet

v3.3y:
- Basis: v3.3x
- TOP-Routing unverändert übernommen
- BOT_COIL_1–4 neu geroutet
- erfolgreiche TOP-Strategie gespiegelt:
  - BOT1/BOT2 primär B.Cu
  - BOT3/BOT4 primär F.Cu
  - BOT2 mit kurzer F.Cu-Brücke
  - BOT4 mit kurzer B.Cu-Brücke
  - insgesamt vier kleine 0.8/0.4-mm-Vias für die beiden lokalen Brücken
- keine Bauteilpositionen verändert
- nächster Schritt: DRC v3.3y

## Update v3.3aa

DRC v3.3z:
- 54 DRC-Verstöße
- 43 offene Verbindungen
- 0 Kurzschlüsse
- 2 Tracks-Crossing-Fehler
- 1 dangling Track bei REED_TILT
- 0 Footprint-Fehler

Verbleibende BOT-Kreuzungen:
- BOT_COIL_1 <-> BOT_COIL_2 auf B.Cu
- BOT_COIL_3 <-> BOT_COIL_4 auf F.Cu

v3.3aa:
- Basis: v3.3z
- TOP-Routing unverändert
- BOT1 und BOT3 bleiben auf ihren bisherigen Lagen
- BOT2 bekommt einen kurzen F.Cu-Brückenabschnitt
- BOT4 bekommt einen kurzen B.Cu-Brückenabschnitt
- insgesamt vier kleine 0.8/0.4-mm-Vias für die beiden lokalen Brücken
- keine Bauteile verschoben
- nächster Schritt: DRC v3.3aa

## Update v3.3ab

DRC v3.3aa:
- 54 DRC-Verstöße
- 43 offene Verbindungen
- 0 Kurzschlüsse
- weiterhin 2 Tracks-Crossing-Fehler
- 1 dangling Track bei REED_TILT
- 0 Footprint-Fehler

Verbleibende BOT-Kreuzungen:
- BOT_COIL_1 <-> BOT_COIL_2
- BOT_COIL_3 <-> BOT_COIL_4

Ursache:
- Die Layer-Brücken in v3.3aa lagen zu spät.
- BOT2 kreuzte BOT1 bereits auf dem senkrechten Abgang direkt unter U5.
- BOT4 kreuzte BOT3 ebenfalls bereits direkt unter U5.

v3.3ab:
- Basis: v3.3aa
- TOP-Routing unverändert
- BOT1 und BOT3 unverändert
- BOT2 wechselt direkt am U5-Ausgang auf F.Cu und bei y=90.4 zurück auf B.Cu
- BOT4 wechselt direkt am U5-Ausgang auf B.Cu und bei y=92.8 zurück auf F.Cu
- keine Bauteile verschoben
- nächster Schritt: DRC v3.3ab

## Update v3.3ak

DRC v3.3ak:
- 52 DRC-Verstöße
- 43 offene Verbindungen
- 0 Kurzschlüsse
- 0 Tracks-Crossing-Fehler
- 0 Clearance-Fehler
- 0 Hole-Clearance-/Hole-to-Hole-Fehler
- 1 dangling Track bei REED_TILT
- übrige DRC-Meldungen sind Bibliotheks-/Silkscreen-Warnungen

Wichtiger Meilenstein:
- TOP_COIL_1–4 sauber geroutet
- BOT_COIL_1–4 sauber geroutet
- U4/J6 und U5/J7 folgen jetzt demselben Routingprinzip
- Coil-Routing damit abgeschlossen

Offene Netze laut DRC betreffen jetzt vor allem:
- GND
- +5V
- +3V3
- STEP_TOP_1–4
- STEP_BOT_1–4
- REED_OPEN
- REED_TILT
- RS485_A / RS485_B / RS485_DE / RS485_RX / RS485_TX
- K1_COIL_LOW / K2_COIL_LOW
- Q1_BASE / Q2_BASE
- ROLL_UP / ROLL_DN

Nächster Schritt:
- offene Logik- und Versorgungssignale blockweise routen
- zuerst STEP_TOP/STEP_BOT, danach RS485/Reed, danach Versorgung/GND

## Update v3.3al

Basis:
- v3.3ak mit sauberem TOP- und BOT-Coil-Routing
- DRC v3.3ak: 0 Kurzschlüsse, 0 Leiterbahnkreuzungen, 0 Clearance-/Hole-Fehler, 43 offene Verbindungen

v3.3al:
- STEP_TOP_1–4 vollständig geroutet
- U1 -> U4
- STEP_TOP_1/2 vollständig auf F.Cu
- STEP_TOP_3/4 überwiegend F.Cu
- kurze B.Cu-Brücken nur zum Überqueren der vorhandenen REED_TILT-Führung
- 0.3-mm-Signalbahnen
- Coil-Routing unverändert
- U5/J7 unverändert

Nächster DRC-Checkpoint:
- STEP_TOP_1–4 prüfen
- danach STEP_BOT_1–4, RS485/Reed und Relaissteuerung weiter routen

## Aktueller Stand v3.3bd

### Bestätigte Meilensteine

v3.3ak:
- TOP_COIL_1–4 sauber
- BOT_COIL_1–4 sauber
- 0 Kurzschlüsse
- 0 Tracks-Crossing
- 0 Clearance-/Hole-Fehler

v3.3as:
- STEP_TOP_1–4 sauber
- 51 DRC-Meldungen, nur Warnungen
- 0 Kurzschlüsse
- 0 Leiterbahnkreuzungen
- 0 Clearance-/Keepout-Fehler
- 40 offene Verbindungen

v3.3az:
- STEP_BOT_1–4 sauber
- TOP/BOT-Coils weiterhin sauber
- STEP_TOP weiterhin sauber
- 51 DRC-Meldungen, nur Warnungen
- 0 echte Routingfehler
- 36 offene Verbindungen

v3.3bc:
- RS485_RX sauber
- RS485_TX sauber
- RS485_DE sauber
- 51 DRC-Meldungen, nur Warnungen
- 0 Kurzschlüsse
- 0 Leiterbahnkreuzungen
- 0 Clearance-/Keepout-Fehler
- 32 offene Verbindungen

### v3.3bd

Datei:
`hardware/Hauptplatine/Hauptplatine_v3.3bd_logic_minimal_150x90.kicad_pcb`

Neu:
- REED_OPEN komplett neu geroutet
- REED_TILT komplett neu geroutet
- J2/J3, R1/R2 und C1/C2 eingebunden
- Coil-, STEP- und RS485_RX/TX/DE-Routing aus den bestätigten sauberen Ständen unverändert

Status:
- DRC v3.3bd steht noch aus
- RS485_A/B bewusst noch offen

### Danach weiter

1. DRC v3.3bd auswerten
2. RS485_A/B separat routen
3. ROLL_UP / ROLL_DN
4. Q1_BASE / Q2_BASE
5. K1_COIL_LOW / K2_COIL_LOW
6. +3V3
7. +5V
8. GND
9. komplette physische Konnektivitätsprüfung
10. finaler DRC
11. separate 230-V-Sicherheitsprüfung
12. Gerber/Drill/BOM

### Wichtig

Der aktuelle Entwicklungsstand ist **keine Fertigungsfreigabe**. Vor Fertigung muss der 230-V-Bereich separat auf Luft-/Kriechstrecken, Absicherung, Leiterbahnbreiten, Schutzmaßnahmen, Relais-/Motorpfade und Bauteileignung geprüft werden.

## Update v3.3bp bis v3.3bt

### Letzter vollständig bestätigter sauberer Stand: v3.3bp

DRC v3.3bp:

- 51 DRC-Meldungen, ausschließlich Bibliotheks-/Silkscreen-Warnungen
- 0 Kurzschlüsse
- 0 Leiterbahnkreuzungen
- 0 Clearance-/Keepout-Fehler
- 0 Hole-/Dangling-Fehler
- 28 offene Verbindungen
- 0 Footprint-Fehler

Zusätzlich abgeschlossen:

- Q1_BASE
- Q2_BASE
- lokale K1_COIL_LOW-Verbindung Q1.1 ↔ D1.2
- lokale K2_COIL_LOW-Verbindung Q2.1 ↔ D2.2

### RS485_A

v3.3bq:
- kompletter A-Versuch bis J4
- offene Verbindungen auf 26 reduziert
- jedoch 7 Leiterbahnkreuzungen, 1 Kurzschluss und 1 Clearance-Fehler
- langer Weg deshalb verworfen

v3.3br:
- nur U3.6 ↔ R3.1 lokal
- 27 offene Verbindungen
- 2 Kurzschlussmeldungen gegen RS485_TX

v3.3bs:
- lokaler A-Weg rechts um U3 herum und unter RS485_TX
- 52 DRC-Meldungen
- 27 offene Verbindungen
- 0 Kurzschlüsse
- 0 Clearance-Fehler
- nur noch 1 Leiterbahnkreuzung gegen GND

v3.3bt:
- aktueller Arbeitsstand
- Basis: v3.3bs
- kurzer Layerwechsel auf B.Cu, um die GND-Leitung zu unterqueren
- danach zurück auf F.Cu zu R3.1
- J4.3 bleibt bewusst offen
- DRC v3.3bt steht noch aus

Datei:
`hardware/Hauptplatine/Hauptplatine_v3.3bt_logic_minimal_150x90.kicad_pcb`

### Aktuell bestätigte saubere Funktionsblöcke

- TOP_COIL_1–4
- BOT_COIL_1–4
- STEP_TOP_1–4
- STEP_BOT_1–4
- RS485_RX
- RS485_TX
- RS485_DE
- Q1_BASE
- Q2_BASE
- lokale K1_COIL_LOW-Verbindung
- lokale K2_COIL_LOW-Verbindung

### Noch offen

- DRC v3.3bt
- RS485_A Restweg zu J4.3
- RS485_B
- REED_OPEN
- REED_TILT
- ROLL_UP
- ROLL_DN
- K1_COIL_LOW Restweg zum Relais
- K2_COIL_LOW Restweg zum Relais
- +3V3
- +5V
- GND
- vollständige physische Konnektivitätsprüfung
- finaler DRC
- separate 230-V-Sicherheitsprüfung
- Gerber/Drill/BOM

### Arbeitsregel

Weiterhin nur ein kleines Netz bzw. eine klar abgegrenzte Teilverbindung pro DRC-Schritt ändern. Saubere Coil-, STEP-, RS485_RX/TX/DE- und Transistor-Basisnetze nicht erneut verändern, solange der DRC dies nicht zwingend erfordert.

Der aktuelle Stand ist keine Fertigungsfreigabe.

## DRC v3.3bt bestätigt

Ergebnis:
- 51 DRC-Meldungen, ausschließlich Bibliotheks-/Silkscreen-Warnungen
- 0 Kurzschlüsse
- 0 Leiterbahnkreuzungen
- 0 Clearance-/Keepout-Fehler
- 0 Hole-/Dangling-Fehler
- 27 offene Verbindungen
- 0 Footprint-Fehler

Damit ist der lokale Abschnitt von RS485_A zwischen U3.6 und R3.1 sauber abgeschlossen.

Weiter offen:
- RS485_A Restweg R3.1 ↔ J4.3
- RS485_B U3.7 ↔ R3.2 ↔ J4.4
- REED_OPEN
- REED_TILT
- ROLL_UP
- ROLL_DN
- K1_COIL_LOW Restweg zum Relais
- K2_COIL_LOW Restweg zum Relais
- +3V3
- +5V
- GND

Aktueller bestätigter Arbeitsstand:
`hardware/Hauptplatine/Hauptplatine_v3.3bt_logic_minimal_150x90.kicad_pcb`

## DRC v3.3bw bestätigt

Ergebnis:
- 51 DRC-Meldungen, nur Bibliotheks-/Silkscreen-Warnungen
- 0 Kurzschlüsse
- 0 Leiterbahnkreuzungen
- 0 Clearance-/Keepout-/Hole-/Dangling-Fehler
- 26 offene Verbindungen
- 0 Footprint-Fehler

RS485_A ist damit vollständig abgeschlossen:
- U3.6 ↔ R3.1
- R3.1 ↔ J4.3

Aktueller bestätigter Stand:
`hardware/Hauptplatine/Hauptplatine_v3.3bw_logic_minimal_150x90.kicad_pcb`

Nächster Block:
- RS485_B U3.7 ↔ R3.2 ↔ J4.4

## DRC v3.3cp bestätigt

Ergebnis:
- 51 DRC-Meldungen, nur Bibliotheks-/Silkscreen-Warnungen
- 0 Kurzschlüsse
- 0 Leiterbahnkreuzungen
- 0 Clearance-/Keepout-/Hole-/Dangling-Fehler
- 24 offene Verbindungen
- 0 Footprint-Fehler

RS485 ist damit vollständig abgeschlossen:
- RX/TX/DE
- A bis J4.3
- B bis J4.4

Aktueller bestätigter Arbeitsstand:
`hardware/Hauptplatine/Hauptplatine_v3.3cp_logic_minimal_150x90.kicad_pcb`

Als nächstes nur REED_OPEN routen und per DRC prüfen; danach REED_TILT.

## Update v3.3eap

Basis:
- Hauptplatine_v3.3eao_logic_repair_150x90.kicad_pcb

Neu:
- ROLL_UP von U1.11 zu R4.1 geroutet
- Start U1.11 bei 90 / 40.70 mm
- F.Cu bis x=128 mm
- kurzer Wechsel auf B.Cu zur Umgehung der dichten RS485-Führung
- Rückwechsel auf F.Cu bei 147 / 48 mm
- Anfahrt von R4.1 über den freien Korridor bei y=54 mm
- 0,30-mm-Signalbahn, zwei 0,8/0,4-mm-Vias
- 230-V-Bereich unverändert
- bestehende Coil-, STEP-, Reed-, RS485- und Versorgungstracks unverändert

Datei:
`hardware/Hauptplatine/Hauptplatine_v3.3eap_logic_repair_150x90.kicad_pcb`

Status:
- DRC für v3.3eap steht noch aus
- ROLL_DN bleibt bis zum DRC dieses Zwischenstands bewusst unverändert

Nächster Schritt:
1. DRC v3.3eap
2. bei sauberem Ergebnis ROLL_DN U1.9 -> R5.1 separat routen
3. danach verbleibende Versorgung/Konnektivität weiter prüfen

Hinweis:
- weiterhin keine Fertigungsfreigabe
- Netzspannungsbereich vor Fertigung separat sicherheitstechnisch prüfen

## Update v3.3eaq

Basis:
- Hauptplatine_v3.3eap_logic_repair_150x90.kicad_pcb

Neu:
- ROLL_DN von U1.9 zu R5.1 geroutet
- Start U1.9 bei 90 / 38.16 mm
- kurzer F.Cu-Abgang nach links bis x=86 mm
- Layerwechsel auf B.Cu und senkrechter Korridor bis y=65.5 mm
- Rückwechsel auf F.Cu und horizontale Führung bis R5.1 bei 134 / 64 mm
- 0,30-mm-Signalbahn, zwei 0,8/0,4-mm-Vias
- statische Prüfung: keine Leiterbahnkreuzung mit vorhandenen Tracks
- statische Prüfung: keine Pad-Kollision im gewählten Korridor
- 230-V-Bereich unverändert
- bestehende Coil-, STEP-, Reed-, RS485-, +5V- und ROLL_UP-Routen unverändert

Datei:
`hardware/Hauptplatine/Hauptplatine_v3.3eaq_logic_repair_150x90.kicad_pcb`

Status:
- ROLL_UP und ROLL_DN sind nun beide geroutet
- KiCad-DRC für v3.3eaq steht noch aus
- keine Fertigungsfreigabe

Nächster Schritt:
1. DRC v3.3eaq
2. danach offene +3V3-, +5V- und GND-Verbindungen systematisch schließen
3. vollständige physische Konnektivitätsprüfung
4. separate 230-V-Sicherheitsprüfung

## Update v3.3ear

Basis:
- Hauptplatine_v3.3eaq_logic_repair_150x90.kicad_pcb
- DRC-Bericht `DRCeaq.rpt` vom 2026-09-29

DRC-Ursachen der letzten ROLL-Routen:
- ROLL_UP kreuzte U1.12
- ROLL_UP kollidierte auf B.Cu mit RS485_DE und J3.2/GND
- ROLL_DN kreuzte U1.31/U1.32

Änderung:
- alte ROLL_UP- und ROLL_DN-Routen vollständig entfernt
- ROLL_UP neu über oberen B.Cu-Randkorridor geführt:
  - U1.11 -> x=84 mm
  - B.Cu über y=21.5 mm bis x=164 mm
  - Rückweg auf F.Cu bei 164/54 mm zu R4.1
- ROLL_DN neu über unteren B.Cu-Korridor geführt:
  - U1.9 -> x=84 mm
  - B.Cu bis y=104 mm, dann nach x=164 mm
  - B.Cu zurück bis 134/66 mm
  - kurzer F.Cu-Anschluss zu R5.1
- 0,30-mm-Signalbahnen, je zwei Vias
- statische Track-/Pad-Kollisionsprüfung der neuen Korridore ohne Treffer
- bestehende 230-V-, Coil-, STEP-, Reed-, RS485- und Versorgungsrouten unverändert

Datei:
`hardware/Hauptplatine/Hauptplatine_v3.3ear_logic_repair_150x90.kicad_pcb`

Nächster Schritt:
1. KiCad-DRC v3.3ear ausführen
2. speziell prüfen, ob ROLL_UP/ROLL_DN nun frei von shorting_items/tracks_crossing/clearance sind
3. anschließend verbleibende DRC-Fehler blockweise reparieren

## Update v3.3eas

Basis:
- Hauptplatine_v3.3ear_logic_repair_150x90.kicad_pcb
- DRCear.rpt vom 2026-09-29: 123 Verstöße
- davon 23 Tracks crossing, 9 shorting_items, 6 clearance, 6 unconnected_items

DRC-Ergebnis für die ROLL-Netze:
- ROLL_UP und ROLL_DN kreuzten sich links
- ROLL_DN kollidierte mit J7.2 / BOT_COIL_3
- ROLL_DN kreuzte K2_COIL_LOW

Änderung:
- alte ROLL_UP-/ROLL_DN-Routen entfernt
- beide Netze neu per zweilagigem, hindernisbewusstem Routing geführt
- Pad-Rotation in KiCad bei der Kollisionsprüfung korrekt berücksichtigt
- vorhandene Tracks, Vias und Pads mit Sicherheitsabstand als Hindernisse behandelt
- statische Prüfung der neuen Routen: 0 Track-, Via- und Pad-Kollisionen

Datei:
`hardware/Hauptplatine/Hauptplatine_v3.3eas_logic_repair_150x90.kicad_pcb`

Nächster Schritt:
1. KiCad-DRC v3.3eas
2. ROLL_UP/ROLL_DN auf shorting_items/tracks_crossing/clearance prüfen
3. danach verbleibende Altfehler priorisieren: STEP_TOP_4, TOP/BOT_COIL, RS485, Versorgung

## Update v3.3eat

Basis:
- Hauptplatine_v3.3eas_logic_repair_150x90.kicad_pcb
- DRCeas.rpt vom 2026-09-29
- DRCeas: 118 Verstöße
- 20 Tracks crossing
- 8 shorting_items
- 7 clearance
- 6 unconnected_items

Wichtige Erkenntnisse aus DRCeas:
- ROLL_DN taucht nicht mehr als Fehler auf
- ROLL_UP hatte nur noch vier Clearance-Verstöße an J2
- STEP_TOP_4 verursachte zahlreiche Kreuzungen mit STEP_TOP_3, STEP_BOT_1..4, RS485_A/B und J4
- TOP_COIL_1..4 und BOT_COIL_1..4 verursachten mehrere Kreuzungen, Shorts und Maskenfehler
- U2 hatte drei eindeutig offene Layerübergänge: +5V an U2.3 sowie beide +3V3-Flächen von U2.2

Änderungen in v3.3eat:
- ROLL_UP im Bereich J2 neu geführt; statische Prüfung ohne Track-/Via-/Pad-Kollision
- STEP_TOP_4 vollständig neu geroutet
- TOP_COIL_1..4 vollständig neu geroutet
- BOT_COIL_1..4 vollständig neu geroutet
- alle neun STEP/COIL-Routen vor Commit zusätzlich geometrisch gegen vorhandene Tracks, Pads und Vias geprüft: 0 erkannte Kollisionen
- +5V-Layerübergang direkt an U2.3 ergänzt
- +3V3-Layerübergänge an beiden U2.2-Padflächen ergänzt
- ROLL_DN unverändert
- 230-V-Bereich unverändert

Datei:
`hardware/Hauptplatine/Hauptplatine_v3.3eat_logic_repair_150x90.kicad_pcb`

Noch bewusst offen:
- GND U1.2
- GND U1.42
- GND U5.8
Diese drei Punkte werden nach dem nächsten KiCad-DRC separat behandelt, da die B.Cu-GND-Zonenfüllung die Bewertung beeinflusst.

Nächster Schritt:
1. Zonen in KiCad neu füllen
2. DRC für v3.3eat ausführen
3. Restfehler aus DRC priorisieren
4. verbleibende GND-Verbindungen schließen
5. abschließende 230-V-Sicherheitsprüfung

## Update v3.3eau

Basis:
- Hauptplatine_v3.3eat_logic_repair_150x90.kicad_pcb
- DRCeat.rpt vom 2026-09-29
- DRCeat: 97 Verstöße
- 8 Tracks crossing
- 6 shorting_items
- 2 clearance
- 1 unconnected_item
- 0 Footprint-Fehler

Wichtige Erkenntnisse:
- nur noch eine offene Verbindung: U1.2 / GND zur LOGIC_GND_PLANE
- RS485_A/B/DE verursachten mehrere Kreuzungen und Shorts
- +3V3 kreuzte /+5V im U2-Bereich
- ROLL_UP/ROLL_DN sowie die neu gerouteten TOP/BOT-Coil-Netze erscheinen im DRCeat nicht mehr als eigene Kurzschluss-/Kreuzungsblöcke

Änderungen in v3.3eau:
- RS485_A vollständig neu geroutet (U3.6, R3.1, J4.3)
- RS485_B vollständig neu geroutet (U3.7, R3.2, J4.4)
- RS485_DE vollständig neu geroutet (U3.2/U3.3 zu U1.25)
- +3V3 vollständig lokal neu aufgebaut zwischen R1, R2, U2.2 und U3.8
- bisherige +3V3-Routen/Vias entfernt, damit der +5V/+3V3-Kurzschluss am U2 entfällt
- explizite GND-Verbindung von U1.2 zu J2.2 ergänzt, damit die letzte offene GND-Verbindung nicht allein von der Zonenfüllung abhängt
- 230-V-Bereich unverändert

Datei:
`hardware/Hauptplatine/Hauptplatine_v3.3eau_logic_repair_150x90.kicad_pcb`

Nächster Schritt:
1. Zonen neu füllen
2. DRC v3.3eau
3. verbleibende Altfehler bei +5V/K1_COIL_LOW, REED_TILT/RS485_TX/STEP_TOP_1 und BOT_COIL_3-Padabstand bereinigen
4. danach Silkscreen-/Library-Warnungen getrennt behandeln

## Update v3.3eav

Basis:
- Hauptplatine_v3.3eau_logic_repair_150x90.kicad_pcb
- DRCeau.rpt vom 2026-09-29
- DRCeau: 105 Verstöße
- 0 unconnected pads
- 0 Footprint-Fehler

Elektrische Restfehler aus DRCeau:
- REED_TILT kurzgeschlossen/gekreuzt mit RS485_TX und STEP_TOP_1
- K1_COIL_LOW kurzgeschlossen/gekreuzt mit +5V
- RS485_B-Via zu nah an U3.2 / RS485_DE
- BOT_COIL_3 zu nah an unbeschaltetem U5.5
- GND-Via im U1-Bereich zu nah an U1.4
- zusätzlich viele reine Warnungen (isolated copper, Library, Silkscreen)

Änderungen in v3.3eav:
- REED_TILT vollständig neu geroutet
- K1_COIL_LOW vollständig neu geroutet
- BOT_COIL_3 vollständig neu geroutet
- RS485_B vollständig neu geroutet; erster Via weiter vom U3-DE-Pad entfernt
- explizite GND-Verbindung U1.2 -> J2.2 im problematischen U1-Bereich neu geführt
- strengere statische Kollisionsprüfung verwendet:
  - Vias gegen beide Kupferlagen geprüft
  - Pads ohne Netz ebenfalls als Hindernisse berücksichtigt
- 230-V-Bereich unverändert

Datei:
`hardware/Hauptplatine/Hauptplatine_v3.3eav_logic_repair_150x90.kicad_pcb`

Status:
- alle Pads elektrisch verbunden
- Routing vollständig; Fokus jetzt auf DRC-Fehlerfreiheit und Warnungsbereinigung
- keine Fertigungsfreigabe

Nächster Schritt:
1. Zonen neu füllen
2. DRC v3.3eav
3. verbleibende elektrische DRC-Fehler beheben
4. danach Warnungen separat priorisieren (GND-Zoneninseln, Silkscreen, fehlende Footprint-Libraries)
5. abschließende 230-V-Sicherheitsprüfung

## Update v3.3eaw

Basis:
- Hauptplatine_v3.3eav_logic_repair_150x90.kicad_pcb
- DRCeav.rpt vom 2026-09-29
- DRCeav: 109 Verstöße
- keine unconnected_items
- 4 Clearance-Fehler
- 1 Tracks crossing
- 1 solder_mask_bridge
- 1 starved_thermal
- Rest überwiegend Warnungen: isolated_copper, lib_footprint_issues, silk_over_copper, silk_overlap

Elektrische Restfehler aus DRCeav:
- K1_COIL_LOW zu nah an J4.1 / +5V
- +5V-B.Cu-Trunk von 162/58 nach 146.92/58 lief durch D1.2 / K1_COIL_LOW
- dadurch Track-Kreuzung und Solder-Mask-Bridge im D1-Bereich

Änderungen in v3.3eaw:
- problematischen +5V-B.Cu-Abschnitt 162/58 -> 146.92/58 entfernt
- +5V im D1-Bereich mit Umfahrung über y=59..60 mm neu geführt
- K1_COIL_LOW vollständig neu geroutet
- K1_COIL_LOW im J4-Bereich konservativer mit größerem Abstand zur rechteckigen J4.1-Kupferfläche geführt
- K1_COIL_LOW im D1/Q1-Bereich unterhalb des neuen +5V-Trunks geführt
- alle Netze weiterhin verbunden
- 230-V-Bereich unverändert

Datei:
`hardware/Hauptplatine/Hauptplatine_v3.3eaw_logic_repair_150x90.kicad_pcb`

Status:
- keine offenen Netze laut DRCeav
- Routing elektrisch vollständig
- v3.3eaw zielt auf Beseitigung der letzten Kurzschluss-/Clearance-/Maskenfehler
- GND-starved-thermal, GND-Zoneninseln, Silkscreen- und Library-Warnungen werden separat bereinigt
- keine Fertigungsfreigabe

Nächster Schritt:
1. Zonen neu füllen
2. DRC v3.3eaw
3. verbleibende echte elektrische Fehler auf 0 bringen
4. GND-Zonenwarnungen bereinigen
5. Silkscreen/Library-Warnungen bereinigen
6. separate 230-V-Sicherheitsprüfung

## Update v3.3eax

Basis:
- Hauptplatine_v3.3eaw_logic_repair_150x90.kicad_pcb
- DRCeaw.rpt vom 2026-09-29
- DRCeaw: 106 Verstöße
- keine unconnected_items
- keine shorting_items
- keine tracks_crossing
- keine clearance-Fehler
- 1 starved_thermal an J3.2/GND
- 50 isolated_copper
- 29 lib_footprint_issues
- 19 silk_over_copper
- 2 holes_co_located
- 2 hole_to_hole
- 2 silk_overlap
- 1 silk_edge_clearance

Änderungen in v3.3eax:
- letzten echten DRC-Fehler starved_thermal an J3.2/GND gezielt adressiert
- J3.2/GND explizit per Leiterbahn zu Q1.3/GND verbunden
- redundanten +5V-Via direkt auf U1.1 entfernt; PTH-Pad verbindet F.Cu/B.Cu bereits selbst
- alte explizite U1.2->J2.2-GND-Hilfsroute entfernt, da deren Via den hole_to_hole-Fehler nahe U1.2 verursachte
- 230-V-Bereich unverändert

Datei:
`hardware/Hauptplatine/Hauptplatine_v3.3eax_logic_repair_150x90.kicad_pcb`

Status:
- alle Netze laut DRC verbunden
- keine Kurzschlüsse/Kreuzungen/Clearance-Fehler in DRCeaw
- v3.3eax zielt auf 0 echte elektrische DRC-Fehler
- verbleibende Meldungen danach voraussichtlich überwiegend Zonen-/Silkscreen-/Library-Warnungen
- keine Fertigungsfreigabe

Nächster Schritt:
1. Zonen neu füllen
2. DRC v3.3eax
3. prüfen, ob starved_thermal und hole-Warnungen verschwunden sind
4. danach GND-Zoneninseln und Silkscreen/Library-Warnungen bereinigen
5. separate 230-V-Sicherheitsprüfung

## Update v3.3eay

Basis:
- Hauptplatine_v3.3eax_logic_repair_150x90.kicad_pcb
- DRCeax.rpt vom 2026-09-29
- DRCeax: 101 DRC-Verstöße + 1 unconnected pad
- keine Kurzschlüsse/Kreuzungen/Clearance-Fehler
- offener Anschluss ausschließlich J2.2 / GND zur LOGIC_GND_PLANE
- 50 isolated_copper
- 29 lib_footprint_issues
- Silkscreen-Warnungen verbleiben

Änderung in v3.3eay:
- J2.2/GND direkt und ohne Via mit J3.2/GND verbunden
- gerade B.Cu-Leiterbahn x=128.08 mm von y=30 mm bis y=45 mm
- keine anderen Netze verändert
- 230-V-Bereich unverändert

Datei:
`hardware/Hauptplatine/Hauptplatine_v3.3eay_logic_repair_150x90.kicad_pcb`

Nächster Schritt:
1. Zonen neu füllen
2. DRC v3.3eay
3. prüfen, ob unconnected_items = 0 bleibt
4. anschließend GND-isolated_copper-Warnungen und Silkscreen/Library-Warnungen bereinigen
5. separate 230-V-Sicherheitsprüfung

## Update v3.3eaz

Basis:
- Hauptplatine_v3.3eay_logic_repair_150x90.kicad_pcb
- Screenshot vom 2026-09-29 zeigte weiterhin mehrere Ratsnest-/Luftlinien

Ursache:
- mehrere bestehende Leiterbahnen endeten nur knapp neben den exakten Padkoordinaten
- typische Abweichungen lagen bei 0,04 bis 0,20 mm
- dadurch wirkten die Netze in einer groben Textprüfung verbunden, KiCad zeigte aber weiterhin Luftlinien

Korrigierte Netze:
- RS485_RX
- RS485_TX
- STEP_TOP_1
- STEP_TOP_2
- STEP_TOP_3
- STEP_BOT_1
- STEP_BOT_2
- STEP_BOT_3
- STEP_BOT_4

Änderung:
- nur kurze Anschlusssegmente von den bisherigen Track-Enden zu den exakten Padkoordinaten ergänzt
- bestehende Hauptrouten unverändert
- 230-V-Bereich unverändert

Datei:
`hardware/Hauptplatine/Hauptplatine_v3.3eaz_logic_repair_150x90.kicad_pcb`

Nächster Schritt:
1. Datei in KiCad öffnen
2. Zonen neu füllen
3. prüfen, ob die sichtbaren Signal-Ratsnest-Linien verschwunden sind
4. DRC ausführen
5. verbleibende GND-/Zonenlinien separat behandeln

## Update v3.3eba

Basis:
- Hauptplatine_v3.3eaz_logic_repair_150x90.kicad_pcb
- Screenshot vom 2026-09-29 zeigte nur noch GND-Ratsnest-Linien

Analyse:
- Signalnetze RS485_RX/TX sowie STEP_TOP_1..3 und STEP_BOT_1..4 sind nach v3.3eaz an exakten Padkoordinaten angeschlossen
- verbleibende getrennte Kupfergruppen gehörten ausschließlich zum GND-Netz
- betroffen: U5.8, U2.1, C2.2, PS1.4, U4.8, Q2.3, U3.5, U1.2, U1.42, C1.2, J4.2
- gemeinsamer GND-Anker: J3.2 / 128.08,45 mm

Änderungen in v3.3eba:
- explizites GND-Backbone ergänzt
- alle oben genannten GND-Pads separat an den gemeinsamen GND-Anker angebunden
- neue GND-Leiterbahnen mit 0,4 mm
- Layerwechsel nur über 0,9/0,45-mm-GND-Vias
- bestehende Signalrouten unverändert
- 230-V-Bereich unverändert

Datei:
`hardware/Hauptplatine/Hauptplatine_v3.3eba_logic_repair_150x90.kicad_pcb`

Nächster Schritt:
1. v3.3eba in KiCad öffnen
2. Zonen neu füllen
3. Ratsnest prüfen — Ziel: 0 sichtbare Luftlinien
4. DRC ausführen
5. anschließend GND-Zoneninseln/Silkscreen/Library-Warnungen bereinigen
6. separate 230-V-Sicherheitsprüfung

## Update v3.3ebb

Basis:
- Hauptplatine_v3.3eba_logic_repair_150x90.kicad_pcb
- DRCeba.rpt vom 2026-09-29
- DRCeba: 131 DRC-Warnungen
- 0 unconnected pads
- keine Kurzschlüsse
- keine Track-Kreuzungen
- keine Clearance-Fehler

Warnungsverteilung:
- 50 isolated_copper
- 30 holes_co_located
- 29 lib_footprint_issues
- 19 silk_over_copper
- 2 silk_overlap
- 1 silk_edge_clearance

Änderung in v3.3ebb:
- doppelte GND-Vias an identischen Koordinaten bereinigt
- 9 tatsächlich redundante GND-Vias entfernt
- die 30 holes_co_located-Warnungen entstanden aus Mehrfachpaarungen dieser doppelten Vias
- elektrische Netze und Signalrouten unverändert
- 230-V-Bereich unverändert

Datei:
`hardware/Hauptplatine/Hauptplatine_v3.3ebb_logic_repair_150x90.kicad_pcb`

Nächster Schritt:
1. Zonen neu füllen
2. DRC v3.3ebb
3. prüfen, ob holes_co_located = 0
4. anschließend 50 isolated_copper-Warnungen der GND-Zone bereinigen
5. danach Silkscreen- und Library-Warnungen
6. separate 230-V-Sicherheitsprüfung

## Update v3.3ebc / v3.3ebd – 230-V-Sicherheitsprüfung

Basis:
- Hauptplatine_v3.3ebb_logic_repair_150x90.kicad_pcb
- Beginn der separaten 230-V-Endprüfung

Mess-/Prüfergebnisse:
- echte 6-mm-Kupfer-Keepout-Zone zwischen Primärseite und SELV vorhanden:
  - x=71..77 mm
  - F.Cu + B.Cu
  - Tracks/Vias/Copperpour verboten
- kleinster gemessener Primär->SELV-Kupferabstand außerhalb PS1/K1/K2 ca. 8,8 mm
- 230-V-Leiterbahnen aktuell 2,0 mm breit
- PS1 Primär-/Sekundär-Padabstand im Footprint >40 mm
- K1/K2 Kontaktseite->Spulenseite im Footprint min. ca. 12,9 mm

v3.3ebc:
- obere AC_L-Führung weiter von oberer Platinenkante nach innen verlegt
- Kupfer->Board-Edge von ca. 1,5 mm auf ca. 3,0 mm verbessert

v3.3ebd:
- kritischen L_PSU_FUSED-Zweig zu PS1 neu geroutet
- vorher ca. 0,3 mm zu PS1.1 / AC_N
- neue Führung links um PS1 herum

Neue Datei:
- `hardware/Hauptplatine/Hauptplatine.kicad_dru`
  - unterschiedliche MAINS-Netze: min. 1,5 mm
  - MAINS->SELV: min. 6 mm
  - MAINS-Trackbreite: min. 2,0 mm
- `hardware/Hauptplatine/230V-SICHERHEITSPRUEFUNG.md`

Statische Prüfung v3.3ebd:
- Primär->SELV weiterhin min. ca. 8,8 mm
- noch 16 Objektpaare unter dem konservativen 1,5-mm-Ziel innerhalb der 230-V-Seite
- Hauptbereiche:
  - AC_L bei F1/RV1
  - AC_L/L_MOTOR/DN_FEED im K1-Bereich
  - DN_FEED/K2.22
  - MOTOR_DN bei J5

Nächster Schritt:
1. v3.3ebd mit Hauptplatine.kicad_dru in KiCad öffnen
2. Design Rule Editor -> Check rule syntax
3. Zonen neu füllen
4. DRC ausführen
5. neuen DRC-Bericht hochladen
6. MAINS-clearance-Fehler einzeln neu routen
7. danach Footprint-Datenblattprüfung und Prototypenfreigabe-Check

Wichtig:
- keine formale Sicherheits-/Fertigungsfreigabe
- 230-V-Sicherheitsprüfung bleibt separat erforderlich

## Update v3.3ebj2 – ESP32-S3 DevKitC-1 Header korrigiert

Basis:
- Hauptplatine_v3.3ebi2_logic_repair_150x90.kicad_pcb

Wichtige Erkenntnis:
- die rechte U1-Headerreihe entspricht sauber dem offiziellen J3-Pinout
- auf der linken U1-Headerreihe waren nur bestimmte Anschlüsse falsch belegt
- die frühere Annahme einer komplett um einen Pin verschobenen linken Reihe war zu grob

Offizielles ESP32-S3-DevKitC-1 J1:
- J1.1/J1.2 = 3V3
- J1.3 = RST
- J1.7 = GPIO7
- J1.8 = GPIO15
- J1.14 = GPIO46 (Input-only, daher ungeeignet für STEP-Ausgang)
- J1.15 = GPIO9
- J1.21 = 5V
- J1.22 = GND

Korrekturen:
- U1.1: +5V entfernt, unbenutzt
- U1.3: STEP_TOP_3 entfernt, unbenutzt
- U1.5: STEP_TOP_2 entfernt, unbenutzt
- U1.13 = STEP_TOP_3 (J1.7 / GPIO7)
- U1.15 = STEP_TOP_2 (J1.8 / GPIO15)
- U1.27 = STEP_TOP_4 entfernt (J1.14 / GPIO46)
- U1.29 = STEP_TOP_4 (J1.15 / GPIO9)
- U1.41 = +5V (J1.21 / 5V)

Routing:
- alte Anschlussstücke zu den falschen Pads entfernt
- STEP_TOP_3 neu zweilagig zu U1.13 geführt
- STEP_TOP_2 neu zweilagig zu U1.15 geführt
- STEP_TOP_4 kurz zu U1.29 umgelegt
- +5V von bestehender +5V-Leitung bei y=90 mm zu U1.41 geführt
- neue statische Kollisionsprüfung: 0 erkannte Track-/Pad-Kollisionen
- alle vier neuen U1-Pads exakt getroffen

Datei:
`hardware/Hauptplatine/Hauptplatine_v3.3ebj2_logic_repair_150x90.kicad_pcb`

Nächster Schritt:
1. v3.3ebj2 in KiCad öffnen
2. Zonen neu füllen
3. DRC ausführen
4. prüfen: 0 unconnected / 0 shorts / 0 crossings / 0 clearance
5. danach verbleibende Warnungen und Gerber-Freigabe

## Update v3.3ebk2 – DRCebj2 elektrische Restfehler behoben

Basis:
- Hauptplatine_v3.3ebj2_logic_repair_150x90.kicad_pcb
- DRCebj2.rpt vom 2026-09-29

DRCebj2:
- 60 DRC-Verstöße
- 3 unconnected pads
- 1 echter Clearance-Fehler
- 5 dangling-track-Warnungen
- Rest Library-/Silkscreen-Warnungen

Behobene elektrische Punkte:
1. REED_OPEN:
   - J2.1 bei 123/30 mm war zwischen zwei alten Track-Ästen nicht verbunden
   - beide Äste direkt zu J2.1 geführt

2. +5V:
   - nach der U1-Pinout-Korrektur war der obere B.Cu-5V-Bus vom übrigen +5V-Netz getrennt
   - Via bei 82.5/50.8 mm ergänzt
   - B.Cu-Verbindung 82.5/50.8 -> 82.5/24 -> 90/24

3. AC_L:
   - bei 66.2/27 mm fehlte der Layerwechsel F.Cu -> B.Cu
   - 1.2/0.6-mm-Via ergänzt

4. K1_COIL_LOW:
   - Clearance zu K2.A2 nur 0.18 mm bei geforderten 0.20 mm
   - lokalen Korridor von y=87.5 mm auf y=89 mm verlegt

Datei:
`hardware/Hauptplatine/Hauptplatine_v3.3ebk2_logic_repair_150x90.kicad_pcb`

Nächster Schritt:
1. v3.3ebk2 öffnen
2. Zonen neu füllen
3. DRC ausführen
4. Ziel: 0 unconnected / 0 clearance / 0 dangling
5. danach nur noch Warnungsbereinigung und Fertigungscheck

## Update v3.3ebl2 – letzter elektrischer Restfehler geschlossen

Basis:
- Hauptplatine_v3.3ebk2_logic_repair_150x90.kicad_pcb
- DRCebk2.rpt vom 2026-09-29

DRCebk2:
- 57 DRC-Verstöße
- 1 unconnected item
- 3 track_dangling-Warnungen
- 0 Footprint-Fehler
- keine Clearance-/Short-/Crossing-Fehler mehr

Letzter echter elektrischer Fehler:
- K1_COIL_LOW war zwischen 81.5/91 und 102/91 unterbrochen
- fehlendes Segment wieder ergänzt

Zusätzliche Bereinigung:
- +5V-Dangling-Junction bei 82.5/58.3 beseitigt
- alte vertikale +5V-Segmente entfernt
- +5V-Bus neu mit explizitem Knoten bei 82.5/50.8 aufgebaut:
  - 82.5/28 -> 82.5/50.8
  - 82.5/50.8 -> 82.5/69
- vorhandener Via bei 82.5/50.8 bleibt Layerübergang zum oberen B.Cu-5V-Bus

Datei:
`hardware/Hauptplatine/Hauptplatine_v3.3ebl2_logic_repair_150x90.kicad_pcb`

Nächster Schritt:
1. Zonen neu füllen
2. finalen DRC v3.3ebl2 ausführen
3. Ziel: 0 unconnected / 0 dangling / 0 electrical errors
4. danach nur noch Silkscreen-/Library-Warnungen und Fertigungscheck

## Update v3.3ebm2 – letzter +5V-Dangling-Endpunkt geschlossen

Basis:
- Hauptplatine_v3.3ebl2_logic_repair_150x90.kicad_pcb
- DRCebl2.rpt vom 2026-09-29

DRCebl2:
- 55 DRC-Warnungen
- 0 unconnected pads
- 0 Footprint-Fehler
- keine Clearance-/Short-/Crossing-Fehler
- nur noch 1 elektrische Warnung:
  - track_dangling bei +5V an 82.5/28 mm
- Rest ausschließlich Library-/Silkscreen-Warnungen

Änderung v3.3ebm2:
- Via bei 82.5/28 mm ergänzt
- B.Cu-Verbindung 82.5/28 -> 82.5/24 ergänzt
- dadurch ist das F.Cu-Ende des +5V-Busses direkt mit dem bestehenden oberen B.Cu-+5V-Bus verbunden

Datei:
`hardware/Hauptplatine/Hauptplatine_v3.3ebm2_logic_repair_150x90.kicad_pcb`

Nächster Schritt:
1. Zonen neu füllen
2. DRC v3.3ebm2
3. Ziel: keine elektrischen DRC-Meldungen mehr
4. danach Silkscreen-/Library-Warnungen bereinigen und Fertigungsdaten prüfen

## Update v3.3ebn2 – elektrisch sauber, Silkscreen-Warnungen bereinigt

Basis:
- Hauptplatine_v3.3ebm2_logic_repair_150x90.kicad_pcb
- DRCebm2.rpt vom 2026-09-29

DRCebm2:
- 54 DRC-Warnungen
- 0 unconnected pads
- 0 Footprint-Fehler
- keine Clearance-/Short-/Crossing-/Dangling-Fehler
- keine elektrischen DRC-Meldungen mehr

Verteilung der verbliebenen Warnungen:
- 21 lib_footprint_mismatch
- 9 lib_footprint_issues (fehlende RolladenCustom-Library)
- 21 silk_over_copper
- 2 silk_overlap
- 1 silk_edge_clearance

Änderungen v3.3ebn2:
- ausschließlich F.SilkS bereinigt
- problematische F.SilkS-Umrisse entfernt bei:
  - RV1
  - F1
  - U2
  - U3
  - D1
  - D2
  - Q1
  - Q2
- kollidierende Referenztexte U2/U3 ausgeblendet
- Kupfer, Pads, Netze und Routing unverändert

Datei:
`hardware/Hauptplatine/Hauptplatine_v3.3ebn2_logic_repair_150x90.kicad_pcb`

Erwarteter nächster DRC:
- 0 elektrische Fehler
- Silkscreen-Warnungen deutlich reduziert bzw. 0
- verbleibend voraussichtlich nur Library-Warnungen

Library-Warnungen:
- nicht elektrisch
- entstehen durch fehlende lokale RolladenCustom-Bibliothek und durch bewusst angepasste eingebettete Footprints
- vor finaler Projektpflege kann eine repository-lokale Footprint-Library aufgebaut und die Footprints damit synchronisiert werden

Nächster Schritt:
1. v3.3ebn2 öffnen
2. Zonen neu füllen
3. DRC ausführen
4. wenn nur Library-Warnungen bleiben: Fertigungs-/Gerber-Check
5. separate 230-V-Sicherheitsprüfung bleibt erforderlich

## Update v3.3ebn2 – DRC elektrisch vollständig sauber

Basis:
- Hauptplatine_v3.3ebn2_logic_repair_150x90.kicad_pcb
- DRCebn2.rpt vom 2026-09-29

DRCebn2:
- 30 DRC-Warnungen
- 0 unconnected pads
- 0 Footprint-Fehler
- keine Clearance-Fehler
- keine Kurzschlüsse
- keine Track-Kreuzungen
- keine Dangling-Tracks
- keine Silkscreen-Warnungen
- keine sonstigen elektrischen DRC-Meldungen

Verbleibend ausschließlich Library-Warnungen:
- 21 lib_footprint_mismatch
- 9 lib_footprint_issues
- Ursache: angepasste lokale Footprints und fehlende RolladenCustom-Library in der lokalen KiCad-Konfiguration
- diese Meldungen sind nicht elektrisch

Aktueller Arbeits-/Fertigungsprüfstand:
`hardware/Hauptplatine/Hauptplatine_v3.3ebn2_logic_repair_150x90.kicad_pcb`

Noch vor Bestellung:
1. repository-lokale Footprint-Library optional sauber aufbauen
2. Gerber/Drill erzeugen
3. Gerber im Viewer prüfen
4. Bohrungen/Boardkontur/Bestückungsseite prüfen
5. BOM gegen tatsächlich bestellte Bauteile abgleichen
6. 230-V-Sicherheitsprüfung separat dokumentiert abschließen
7. erste Inbetriebnahme ohne Netzspannung

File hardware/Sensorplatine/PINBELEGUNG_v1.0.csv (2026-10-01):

Signal | STM32 Pin | Physical Pin | Peripheral | Destination | Notes
I2C_SDA | PB9 | 1 | I2C1 | BME280;SCD41;SGP40;VEML7700 | 4.7k pull-up to 3V3
I2C_SCL | PB8 | 28 | I2C1 | BME280;SCD41;SGP40;VEML7700 | 4.7k pull-up to 3V3
LD2450_TX | PA2 | 9 | USART2_TX | HLK-LD2450_RX | 3.3V UART
LD2450_RX | PA3 | 10 | USART2_RX | HLK-LD2450_TX | 3.3V UART
I2S_WS | PA4 | 11 | SPI1/I2S1 | Microphone_WS | AF0 verified
I2S_CK | PA5 | 12 | SPI1/I2S1 | Microphone_CK | AF0 verified
I2S_SD | PA7 | 14 | SPI1/I2S1 | Microphone_SD | AF0 verified
RS485_DE | PB1 | 16 | GPIO | MAX3485_DE_RE | 10k pull-down
RS485_TX | PB6 | 32 | USART1_TX | MAX3485_DI
RS485_RX | PB7 | 27 | USART1_RX | MAX3485_RO
SWDIO | PA13 | 24 | SWD | SWD_Header
SWCLK | PA14 | 25 | SWD | SWD_Header
NRST | PF2-NRST | 6 | Reset | SWD_Header | 10k pull-up to 3V3

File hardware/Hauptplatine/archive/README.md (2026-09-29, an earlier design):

# Archiv – Hauptplatine

Dieser Ordner enthält historische KiCad-PCB-Zwischenstände der Hauptplatine.

Aktiver Stand:

`../Hauptplatine_v3.3ebn2_logic_repair_150x90.kicad_pcb`

Die Dateien im Archiv dienen nur der Entwicklungsnachvollziehbarkeit und sollen nicht für neue Fertigungsdaten verwendet werden.

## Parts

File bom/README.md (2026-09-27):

# BOM

Hier wird die Stückliste für die Fertigung gepflegt. Die finale BOM wird erst mit einer freigegebenen Hardwareversion erzeugt.

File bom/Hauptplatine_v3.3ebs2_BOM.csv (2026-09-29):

Qty | References | Value | Footprint | Verification
2 | C1 C2 | 100n | Fenstersteuerung:C_0805_2012Metric | Project-local footprint
1 | C3 | 22uF 10V TANT | Fenstersteuerung:CP_EIA-3528-21_Kemet-B | AMS1117 output stabilization capacitor; project-local footprint
2 | D1 D2 | 1N4007 | Fenstersteuerung:D_DO-41_SOD81_P10.16mm_Horizontal | Project-local footprint
1 | F1 | T1A | Fenstersteuerung:Littelfuse_646_5x20 | Footprint corrected to Littelfuse 646 5x20 holder; verify purchased part before assembly
1 | F2 | T2A | Fenstersteuerung:Littelfuse_646_5x20 | Footprint corrected to Littelfuse 646 5x20 holder; verify purchased part before assembly
1 | J1 | 230V IN L/N/PE | Fenstersteuerung:Phoenix_MKDS-1.5_3P_P5.08 | Project-local footprint; verify exact terminal block variant
1 | J2 | REED OFFEN | Fenstersteuerung:Phoenix_MKDS-1.5_2P_P5.08 | Project-local footprint; verify exact terminal block variant
1 | J3 | REED GEKIPPT | Fenstersteuerung:Phoenix_MKDS-1.5_2P_P5.08 | Project-local footprint; verify exact terminal block variant
1 | J4 | RS485 5V/GND/A/B | Fenstersteuerung:Phoenix_MKDS-1.5_4P_P5.08 | Project-local footprint; verify exact terminal block variant
1 | J5 | MOTOR N/PE/AUF/AB | Fenstersteuerung:Phoenix_MKDS-1.5_4P_P5.08 | Project-local footprint; verify exact terminal block variant
1 | J6 | 28BYJ-48 OBEN | Fenstersteuerung:JST_XH_B5B-XH-A_1x05_P2.50mm_Vertical | Project-local footprint
1 | J7 | 28BYJ-48 UNTEN | Fenstersteuerung:JST_XH_B5B-XH-A_1x05_P2.50mm_Vertical | Project-local footprint
1 | K1 | Finder 40.52.9.005.0000 AUF | Fenstersteuerung:Relay_DPDT_Finder_40.52 | Official Finder 40.52 pin grid reflected in footprint
1 | K2 | Finder 40.52.9.005.0000 AB | Fenstersteuerung:Relay_DPDT_Finder_40.52 | Official Finder 40.52 pin grid reflected in footprint
1 | PS1 | IRM-20-5 | Fenstersteuerung:Converter_ACDC_MeanWell_IRM-20-xx_THT | Footprint and pin mapping corrected for Mean Well IRM-20-5
1 | Q1 | BC337 AUF | Fenstersteuerung:TO-92_Inline_Wide | Project-local footprint
1 | Q2 | BC337 AB | Fenstersteuerung:TO-92_Inline_Wide | Project-local footprint
2 | R1 R2 | 10k | Fenstersteuerung:R_0805_2012Metric | Project-local footprint
1 | R3 | 120R TERM | Fenstersteuerung:R_0805_2012Metric | RS485 termination resistor
2 | R4 R5 | 470R | Fenstersteuerung:R_0805_2012Metric | Project-local footprint
1 | RV1 | MOV 275VAC | Fenstersteuerung:MOV_S14K275_P7.5 | TDK/EPCOS S14K275-style 7.5 mm lead pitch; verify exact purchased part
1 | U1 | ESP32-S3 DevKitC-1 headers | Fenstersteuerung:ESP32-S3_DevKitC-1_Carrier | DevKitC-1 pin mapping corrected; verify exact ESP32-S3 DevKitC-1 board revision
1 | U2 | AMS1117-3.3 | Fenstersteuerung:SOT-223-3_TabPin2 | Project-local footprint
1 | U3 | MAX3485 | Fenstersteuerung:SOIC-8_3.9x4.9mm_P1.27mm | Project-local footprint
1 | U4 | ULN2003A OBEN | Fenstersteuerung:DIP-16_W7.62mm | Project-local footprint
1 | U5 | ULN2003A UNTEN | Fenstersteuerung:DIP-16_W7.62mm | Project-local footprint

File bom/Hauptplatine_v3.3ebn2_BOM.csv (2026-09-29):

Qty | References | Value | Footprint | Verification
2 | C1 C2 | 100n | Capacitor_SMD:C_0805_2012Metric
1 | C3 | 22uF 10V TANT | Capacitor_Tantalum_SMD:CP_EIA-3528-21_Kemet-B | AMS1117 output stabilization capacitor
2 | D1 D2 | 1N4007 | Diode_THT:D_DO-41_SOD81_P10.16mm_Horizontal
1 | F1 | T1A | RolladenCustom:Littelfuse_646_5x20 | Local/custom footprint - verify against purchased part
1 | F2 | T2A | RolladenCustom:Littelfuse_646_5x20 | Local/custom footprint - verify against purchased part
1 | J1 | 230V IN L/N/PE | RolladenCustom:Phoenix_MKDS-1.5_3P_P5.08 | Local/custom footprint - verify against purchased part
1 | J2 | REED OFFEN | RolladenCustom:Phoenix_MKDS-1.5_2P_P5.08 | Local/custom footprint - verify against purchased part
1 | J3 | REED GEKIPPT | RolladenCustom:Phoenix_MKDS-1.5_2P_P5.08 | Local/custom footprint - verify against purchased part
1 | J4 | RS485 5V/GND/A/B | RolladenCustom:Phoenix_MKDS-1.5_4P_P5.08 | Local/custom footprint - verify against purchased part
1 | J5 | MOTOR N/PE/AUF/AB | RolladenCustom:Phoenix_MKDS-1.5_4P_P5.08 | Local/custom footprint - verify against purchased part
1 | J6 | 28BYJ-48 OBEN | Connector_JST:JST_XH_B5B-XH-A_1x05_P2.50mm_Vertical
1 | J7 | 28BYJ-48 UNTEN | Connector_JST:JST_XH_B5B-XH-A_1x05_P2.50mm_Vertical
1 | K1 | Finder 40.52.9.005.0000 AUF | Relay_THT:Relay_DPDT_Finder_40.52 | Verified footprint grid against Finder 40.52
1 | K2 | Finder 40.52.9.005.0000 AB | Relay_THT:Relay_DPDT_Finder_40.52 | Verified footprint grid against Finder 40.52
1 | PS1 | IRM-20-5 | Converter_ACDC:Converter_ACDC_MeanWell_IRM-20-xx_THT | Verified footprint/pin mapping against Mean Well IRM-20-5
1 | Q1 | BC337 AUF | Package_TO_SOT_THT:TO-92_Inline_Wide
1 | Q2 | BC337 AB | Package_TO_SOT_THT:TO-92_Inline_Wide
2 | R1 R2 | 10k | Resistor_SMD:R_0805_2012Metric
1 | R3 | 120R TERM | Resistor_SMD:R_0805_2012Metric
2 | R4 R5 | 470R | Resistor_SMD:R_0805_2012Metric
1 | RV1 | MOV 275VAC | RolladenCustom:MOV_S14K275_P7.5 | Local/custom footprint - verify against purchased part
1 | U1 | ESP32-S3 DevKitC-1 headers | RolladenCustom:ESP32-S3_DevKitC-1_Carrier | Local/custom footprint - pin mapping corrected for DevKitC-1
1 | U2 | AMS1117-3.3 | Package_TO_SOT_SMD:SOT-223-3_TabPin2
1 | U3 | MAX3485 | Package_SO:SOIC-8_3.9x4.9mm_P1.27mm
1 | U4 | ULN2003A OBEN | Package_DIP:DIP-16_W7.62mm
1 | U5 | ULN2003A UNTEN | Package_DIP:DIP-16_W7.62mm

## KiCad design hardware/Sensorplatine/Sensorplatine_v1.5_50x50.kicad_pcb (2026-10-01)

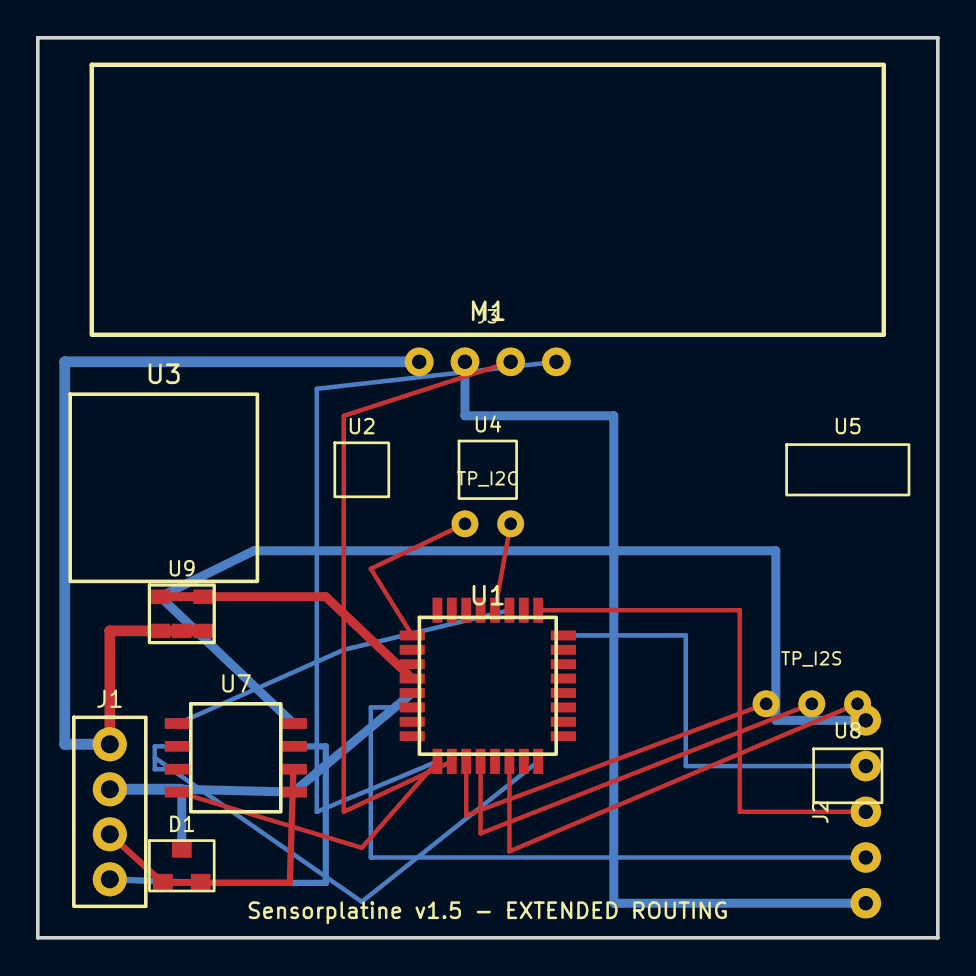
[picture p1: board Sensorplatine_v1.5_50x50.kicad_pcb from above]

Board: 2 copper layers, 50.0 x 50.0 mm, 15 parts (0 on the bottom side), 18 nets.

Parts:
D1: SM712; SM712_SOT23
J1: 5V/GND/A/B; JST_XH_1x04
J2: SWD; SWD_1x05
J3: LD2450 temporary interface; LD2450_IF
M1: HLK-LD2450; HLK_LD2450
TP_I2C: I2C trunk to sensor zone; I2C_TEMP_TERMINALS
TP_I2S: I2S trunk to microphone zone; I2S_TEMP_TERMINALS
U1: STM32G031K8T6; STM32G031K8T6_LQFP32
U2: BME280 - LANDPATTERN TODO; BME280_PLACEHOLDER
U3: SCD41 - LANDPATTERN TODO; SCD41_PLACEHOLDER
U4: SGP40 - LANDPATTERN TODO; SGP40_PLACEHOLDER
U5: VEML7700 - LANDPATTERN TODO; VEML7700_PLACEHOLDER
U7: MAX3485; MAX3485_SOIC8
U8: T5848 - LANDPATTERN TODO; T5848_PLACEHOLDER
U9: AP2112K-3.3; AP2112K_SOT23-5

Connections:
+3V3: J2.1, U1.4, U7.8, U9.5
+5V: J1.1, J3.1, U9.1, U9.3
GND: D1.3, J1.2, J2.5, J3.2, U1.5, U7.5, U9.2
I2C_SCL: TP_I2C.2, U1.28
I2C_SDA: TP_I2C.1, U1.1
I2S_CK: TP_I2S.2, U1.12
I2S_SD: TP_I2S.3, U1.14
I2S_WS: TP_I2S.1, U1.11
LD2450_RX: J3.4, U1.9
LD2450_TX: J3.3, U1.10
NRST: J2.4, U1.6
RS485_A: D1.1, J1.3, U7.6
RS485_B: D1.2, J1.4, U7.7
RS485_DE: U1.16, U7.2, U7.3
RS485_RX: U1.27, U7.1
RS485_TX: U1.32, U7.4
SWCLK: J2.3, U1.25
SWDIO: J2.2, U1.24

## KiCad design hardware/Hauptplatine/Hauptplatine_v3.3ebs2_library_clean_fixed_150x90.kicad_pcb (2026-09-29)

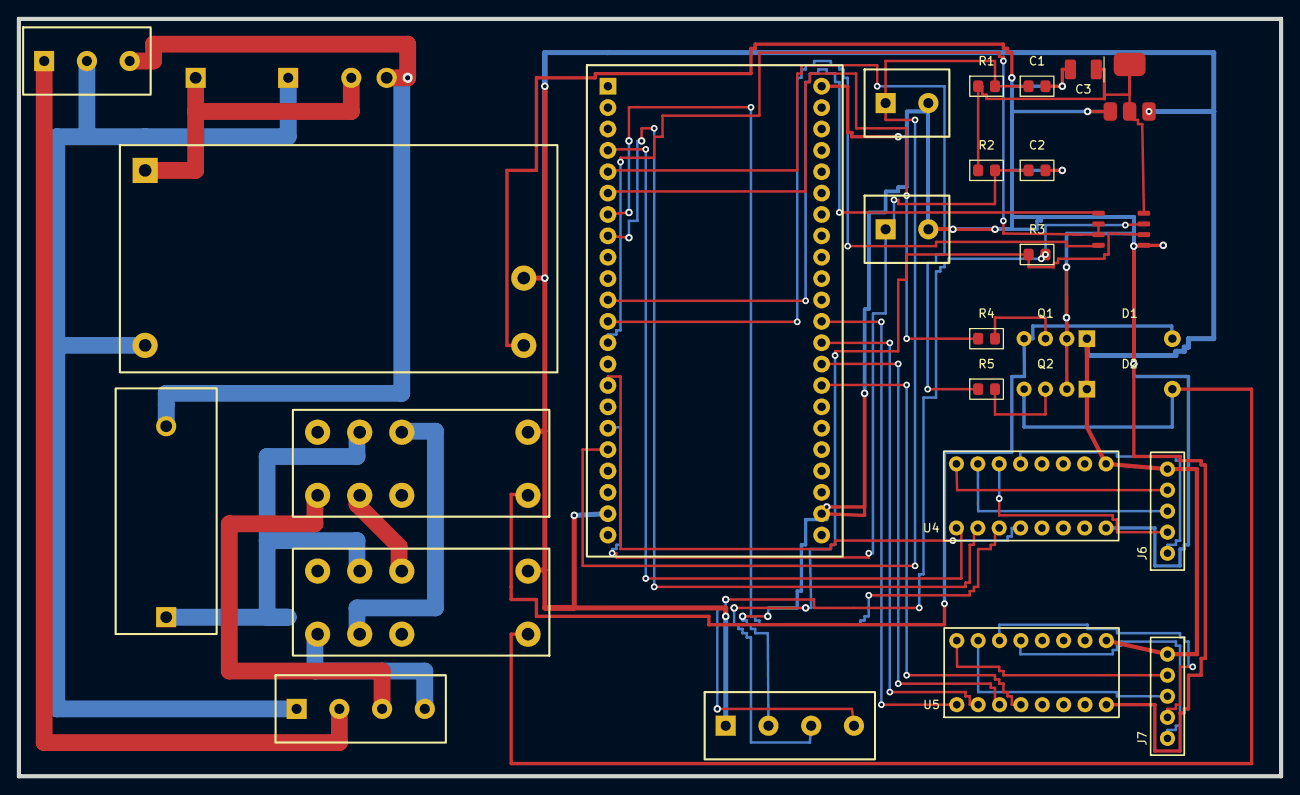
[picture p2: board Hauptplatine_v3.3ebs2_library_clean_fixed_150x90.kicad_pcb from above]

Board: 2 copper layers, 150.0 x 90.0 mm, 30 parts (0 on the bottom side), 41 nets.

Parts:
C1, C2: 100n; C_0805_2012Metric
C3: 22uF 10V TANT; CP_EIA-3528-21_Kemet-B
D1, D2: 1N4007; D_DO-41_SOD81_P10.16mm_Horizontal
F1: T1A; Littelfuse_646_5x20
F2: T2A; Littelfuse_646_5x20
J1: 230V IN L/N/PE; Phoenix_MKDS-1.5_3P_P5.08
J2: REED OFFEN; Phoenix_MKDS-1.5_2P_P5.08
J3: REED GEKIPPT; Phoenix_MKDS-1.5_2P_P5.08
J4: RS485 5V/GND/A/B; Phoenix_MKDS-1.5_4P_P5.08
J5: MOTOR N/PE/AUF/AB; Phoenix_MKDS-1.5_4P_P5.08
J6: 28BYJ-48 OBEN; JST_XH_B5B-XH-A_1x05_P2.50mm_Vertical
J7: 28BYJ-48 UNTEN; JST_XH_B5B-XH-A_1x05_P2.50mm_Vertical
K1: Finder 40.52.9.005.0000 AUF; Relay_DPDT_Finder_40.52
K2: Finder 40.52.9.005.0000 AB; Relay_DPDT_Finder_40.52
PS1: IRM-20-5; Converter_ACDC_MeanWell_IRM-20-xx_THT
Q1: BC337 AUF; TO-92_Inline_Wide
Q2: BC337 AB; TO-92_Inline_Wide
R1, R2: 10k; R_0805_2012Metric
R3: 120R TERM; R_0805_2012Metric
R4, R5: 470R; R_0805_2012Metric
RV1: MOV 275VAC; MOV_S14K275_P7.5
U1: ESP32-S3 DevKitC-1 headers; ESP32-S3_DevKitC-1_Carrier
U2: AMS1117-3.3; SOT-223-3_TabPin2
U3: MAX3485; SOIC-8_3.9x4.9mm_P1.27mm
U4: ULN2003A OBEN; DIP-16_W7.62mm
U5: ULN2003A UNTEN; DIP-16_W7.62mm

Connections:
/+3V3: C3.1, R1.1, R2.1, U2.2, U3.8
/+5V: D1.1, D2.1, J4.1, J6.5, J7.5, K1.A2, K2.A2, PS1.4 (+Vo), U1.41, U2.3, U4.9, U5.9
/AC_L: F1.2, F2.2, J1.3
/AC_N: J1.2, J5.1, PS1.2 (AC/N), RV1.1
/BOT_COIL_1: J7.4, U5.16
/BOT_COIL_2: J7.3, U5.15
/BOT_COIL_3: J7.2, U5.14
/BOT_COIL_4: J7.1, U5.13
/DN_FEED: K1.22, K2.11
/GND: C1.2, C2.2, C3.2, J2.2, J3.2, J4.2, PS1.3 (-Vo), Q1.3, Q2.3, U1.2, U1.42, U2.1, U3.5, U4.8, U5.8
/K1_COIL_LOW: D1.2, K1.A1, Q1.1
/K2_COIL_LOW: D2.2, K2.A1, Q2.1
/L_MOTOR: F2.1, K1.21, K2.21
/L_PSU_FUSED: F1.1, PS1.1 (AC/L), RV1.2
/MOTOR_DN: J5.4, K2.14
/MOTOR_UP: J5.3, K1.14
/PE: J1.1, J5.2
/Q1_BASE: Q1.2, R4.2
/Q2_BASE: Q2.2, R5.2
/REED_OPEN: C1.1, J2.1, R1.2, U1.35
/REED_TILT: C2.1, J3.1, R2.2, U1.33
/ROLL_DN: R5.1, U1.9
/ROLL_UP: R4.1, U1.11
/RS485_A: J4.3, R3.1, U3.6
/RS485_B: J4.4, R3.2, U3.7
/RS485_DE: U1.25, U3.2, U3.3
/RS485_RX: U1.21, U3.1
/RS485_TX: U1.23, U3.4
/STEP_BOT_1: U1.24, U5.1
/STEP_BOT_2: U1.26, U5.2
/STEP_BOT_3: U1.28, U5.3
/STEP_BOT_4: U1.30, U5.4
/STEP_TOP_1: U1.7, U4.1
/STEP_TOP_2: U1.15, U4.2
/STEP_TOP_3: U1.13, U4.3
/STEP_TOP_4: U1.29, U4.4
/TOP_COIL_1: J6.4, U4.16
/TOP_COIL_2: J6.3, U4.15
/TOP_COIL_3: J6.2, U4.14
/TOP_COIL_4: J6.1, U4.13
/UP_FEED: K1.11, K2.22

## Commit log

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2026-09-27 hardware: correct TOP and BOT coil routing endpoints in v3.3h
    [Hauptplatine_v3.3h_logic_minimal_150x90.kicad_pcb]
2026-09-27 hardware: reroute TOP and BOT coils with right-side fanout in v3.3i
    [Hauptplatine_v3.3i_logic_minimal_150x90.kicad_pcb]
2026-09-27 hardware: route TOP coils using corrected rotated pad coordinates in v3.3j
    [Hauptplatine_v3.3j_logic_minimal_150x90.kicad_pcb]
2026-09-27 hardware: correct TOP coil coordinates from KiCad DRC in v3.3k
    [Hauptplatine_v3.3k_logic_minimal_150x90.kicad_pcb]
2026-09-27 hardware: reroute TOP coils with separated layer corridors in v3.3l
    [Hauptplatine_v3.3l_logic_minimal_150x90.kicad_pcb]
2026-09-27 hardware: route TOP coils with remote via escape in v3.3m
    [Hauptplatine_v3.3m_logic_minimal_150x90.kicad_pcb]
2026-09-27 hardware: move TOP coil corridors right of J6 in v3.3n
    [Hauptplatine_v3.3n_logic_minimal_150x90.kicad_pcb]
2026-09-27 hardware: reroute TOP coils in paired escape corridors v3.3o
    [Hauptplatine_v3.3o_logic_minimal_150x90.kicad_pcb]
2026-09-27 hardware: remove final TOP coil crossings in v3.3p
    [Hauptplatine_v3.3p_logic_minimal_150x90.kicad_pcb]
2026-09-27 hardware: rotate J6 and simplify TOP coil routing in v3.3q
    [Hauptplatine_v3.3q_logic_minimal_150x90.kicad_pcb]
2026-09-27 hardware: move rotated J6 clear of U4 and reroute TOP coils in v3.3r
    [Hauptplatine_v3.3r_logic_minimal_150x90.kicad_pcb]
2026-09-27 hardware: return to v3.3o geometry and resolve TOP crossings with local layer hops in v3.3s
    [Hauptplatine_v3.3s_logic_minimal_150x90.kicad_pcb]
2026-09-27 hardware: remap J6 coil pin order and simplify TOP routing in v3.3t
    [Hauptplatine_v3.3t_logic_minimal_150x90.kicad_pcb]
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2026-09-27 hardware: escape TOP coils vertically from U4 pad field in v3.3u
    [Hauptplatine_v3.3u_logic_minimal_150x90.kicad_pcb]
2026-09-27 hardware: move K2 driver row and open TOP routing corridor in v3.3v
    [Hauptplatine_v3.3v_logic_minimal_150x90.kicad_pcb]
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2026-09-27 hardware: remove final TOP pair crossings in v3.3w
    [Hauptplatine_v3.3w_logic_minimal_150x90.kicad_pcb]
2026-09-27 docs: record v3.3v DRC and v3.3w final TOP crossing fix
2026-09-27 hardware: bridge final TOP crossings with local layer hops in v3.3x
    [Hauptplatine_v3.3x_logic_minimal_150x90.kicad_pcb]
2026-09-27 hardware: route BOT coils using proven local bridge strategy in v3.3y
    [Hauptplatine_v3.3y_logic_minimal_150x90.kicad_pcb]
2026-09-27 hardware: reroute BOT coils around J7 in v3.3z
    [Hauptplatine_v3.3z_logic_minimal_150x90.kicad_pcb]
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2026-09-27 hardware: move BOT layer hops to U5 outputs in v3.3ab
    [Hauptplatine_v3.3ab_logic_minimal_150x90.kicad_pcb]
2026-09-27 hardware: fix BOT crossings without vias on U5 pads in v3.3ac
    [Hauptplatine_v3.3ac_logic_minimal_150x90.kicad_pcb]
2026-09-27 hardware: move BOT4 vias away from BOT2/BOT3 in v3.3ad
    [Hauptplatine_v3.3ad_logic_minimal_150x90.kicad_pcb]
2026-09-27 hardware: reroute BOT4 away from U5 pad row in v3.3ae
    [Hauptplatine_v3.3ae_logic_minimal_150x90.kicad_pcb]
2026-09-27 hardware: move BOT4 vias into clear corridor in v3.3af
    [Hauptplatine_v3.3af_logic_minimal_150x90.kicad_pcb]
2026-09-27 hardware: move final BOT4 layer hop beyond BOT2 in v3.3ag
    [Hauptplatine_v3.3ag_logic_minimal_150x90.kicad_pcb]
2026-09-27 hardware: move BOT4 hop left of J7 in v3.3ah
    [Hauptplatine_v3.3ah_logic_minimal_150x90.kicad_pcb]
2026-09-27 hardware: route BOT4 entirely on B.Cu outside J7 in v3.3ai
    [Hauptplatine_v3.3ai_logic_minimal_150x90.kicad_pcb]
2026-09-27 hardware: move U5/J7 down and mirror U4 routing in v3.3aj
    [Hauptplatine_v3.3aj_logic_minimal_150x90.kicad_pcb]
2026-09-27 hardware: mirror U4 TOP routing exactly for U5 BOT in v3.3ak
    [Hauptplatine_v3.3ak_logic_minimal_150x90.kicad_pcb]
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2026-09-27 hardware: reroute STEP_TOP below GND corridor in v3.3am
    [Hauptplatine_v3.3am_logic_minimal_150x90.kicad_pcb]
2026-09-27 hardware: reroute STEP_TOP in isolated left corridors in v3.3an
    [Hauptplatine_v3.3an_logic_minimal_150x90.kicad_pcb]
2026-09-27 hardware: reroute STEP_TOP in clean B.Cu corridor in v3.3ao
    [Hauptplatine_v3.3ao_logic_minimal_150x90.kicad_pcb]
2026-09-27 hardware: correct rotated U4 STEP input coordinates in v3.3ap
    [Hauptplatine_v3.3ap_logic_minimal_150x90.kicad_pcb]
2026-09-27 hardware: fix STEP_TOP pad targets and split routing layers in v3.3aq
    [Hauptplatine_v3.3aq_logic_minimal_150x90.kicad_pcb]
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2026-09-27 hardware: move STEP_TOP_4 U1 escape to F.Cu in v3.3as
    [Hauptplatine_v3.3as_logic_minimal_150x90.kicad_pcb]
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2026-09-27 hardware: reroute STEP_BOT across GND on B.Cu in v3.3au
    [Hauptplatine_v3.3au_logic_minimal_150x90.kicad_pcb]
2026-09-27 hardware: move STEP_BOT_1 via away from GND in v3.3av
    [Hauptplatine_v3.3av_logic_minimal_150x90.kicad_pcb]
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2026-09-27 hardware: keep clean RS485 RX TX DE and defer A B in v3.3bc
    [Hauptplatine_v3.3bc_logic_minimal_150x90.kicad_pcb]
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2026-09-27 hardware: refine REED routing and avoid J2 J3 pad conflicts in v3.3bh
    [Hauptplatine_v3.3bh_logic_minimal_150x90.kicad_pcb]
2026-09-27 hardware: fix final REED collisions in v3.3bi
    [Hauptplatine_v3.3bi_logic_minimal_150x90.kicad_pcb]
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2026-09-27 hardware: route Q1 Q2 base nets around transistor pad 1 in v3.3bm
    [Hauptplatine_v3.3bm_logic_minimal_150x90.kicad_pcb]
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2026-09-27 hardware: route local K1 K2 coil-low nets around neighboring pads in v3.3bo
    [Hauptplatine_v3.3bo_logic_minimal_150x90.kicad_pcb]
2026-09-27 hardware: increase K1 K2 coil-low clearance from diode +5V pads in v3.3bp
    [Hauptplatine_v3.3bp_logic_minimal_150x90.kicad_pcb]
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2026-09-27 hardware: fix local RS485_A GND crossing with layer change in v3.3bt
    [Hauptplatine_v3.3bt_logic_minimal_150x90.kicad_pcb]
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2026-09-27 hardware: reroute RS485_A from R3 to J4 via clear mid-board corridor in v3.3bv
    [Hauptplatine_v3.3bv_logic_minimal_150x90.kicad_pcb]
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2026-09-27 hardware: increase RS485_B via clearance from GND in v3.3bz
    [Hauptplatine_v3.3bz_logic_minimal_150x90.kicad_pcb]
2026-09-27 hardware: fix final local RS485_B clearance in v3.3ca
    [Hauptplatine_v3.3ca_logic_minimal_150x90.kicad_pcb]
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2026-09-27 hardware: inset RS485_B perimeter route for edge and GND clearance in v3.3ch
    [Hauptplatine_v3.3ch_logic_minimal_150x90.kicad_pcb]
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2026-09-27 hardware: resolve final RS485_A/B crossings in v3.3cj
    [Hauptplatine_v3.3cj_logic_minimal_150x90.kicad_pcb]
2026-09-27 hardware: resolve RS485_B crossings with early layer change in v3.3ck
    [Hauptplatine_v3.3ck_logic_minimal_150x90.kicad_pcb]
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2026-09-27 hardware: fix final RS485_B GND clearance in v3.3cm
    [Hauptplatine_v3.3cm_logic_minimal_150x90.kicad_pcb]
2026-09-27 hardware: fix final RS485_B GND short in v3.3cn
    [Hauptplatine_v3.3cn_logic_minimal_150x90.kicad_pcb]
2026-09-27 hardware: add v3.3co RS485_B clearance fix
    [Hauptplatine_v3.3co_logic_minimal_150x90.kicad_pcb]
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2026-09-28 PCB v3.3cz: fix REED_OPEN routing and compact mains area
    [Hauptplatine_v3.3cz_logic_minimal_150x90.kicad_pcb]
2026-09-28 Fix v3.3cz rebuild from cy: safe REED route and compact mains layout
    [Hauptplatine_v3.3cz_logic_minimal_150x90.kicad_pcb]
2026-09-28 PCB v3.3da: fix J5 rerouting and REED_OPEN GND crossings
    [Hauptplatine_v3.3da_logic_minimal_150x90.kicad_pcb]
2026-09-28 PCB v3.3db: shift 6mm SELV zone left, move PSU, fix critical DRC and signal routes
    [Hauptplatine_v3.3db_logic_minimal_150x90.kicad_pcb]
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2026-09-28 PCB v3.3dh: targeted repair from v3.3df for mains, relay and REED_OPEN DRC faults
    [Hauptplatine_v3.3dh_logic_minimal_150x90.kicad_pcb]
2026-09-28 PCB v3.3di: fix REED/GND crossings and reconnect remaining logic nets
    [Hauptplatine_v3.3di_logic_minimal_150x90.kicad_pcb]
2026-09-28 PCB v3.3dj: controlled DRC repair from v3.3dh for REED_OPEN, 3V3 and local GND
    [Hauptplatine_v3.3dj_logic_minimal_150x90.kicad_pcb]
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2026-09-28 PCB v3.3dm: fix final REED_OPEN, 3V3 and edge-clearance routing errors
    [Hauptplatine_v3.3dm_logic_minimal_150x90.kicad_pcb]
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2026-09-28 PCB v3.3dt: fix final REED_OPEN and 3V3 crossings
    [Hauptplatine_v3.3dt_logic_minimal_150x90.kicad_pcb]
2026-09-28 PCB v3.3du: resolve remaining REED_OPEN and 3V3 DRC errors
    [Hauptplatine_v3.3du_logic_minimal_150x90.kicad_pcb]
2026-09-28 PCB v3.3dv: local repair of the two v3.3dt routing errors
    [Hauptplatine_v3.3dv_logic_minimal_150x90.kicad_pcb]
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2026-09-28 PCB v3.3dx: clear final REED_OPEN clearance and close two local nets
    [Hauptplatine_v3.3dx_logic_minimal_150x90.kicad_pcb]
2026-09-28 PCB v3.3dy: clear final via clearance and close local GND/REED_TILT nets
    [Hauptplatine_v3.3dy_logic_minimal_150x90.kicad_pcb]
2026-09-28 PCB v3.3dz: fix final REED_OPEN clearance from stable v3.3dx
    [Hauptplatine_v3.3dz_logic_minimal_150x90.kicad_pcb]
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2026-09-28 PCB v3.3dzd: move REED_OPEN around 3V3 and C2 GND clearance
    [Hauptplatine_v3.3dzd_logic_minimal_150x90.kicad_pcb]
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2026-09-28 PCB v3.3dzi: compact logic placement 8mm left and reset SELV routing
    [Hauptplatine_v3.3dzi_logic_compact_150x90.kicad_pcb]
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2026-09-28 PCB v3.3dzl: reroute compact logic with pad-aware clearances
    [Hauptplatine_v3.3dzl_logic_compact_routed_150x90.kicad_pcb]
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2026-09-28 PCB v3.3dzo: reroute logic with full via and track clearance reservation
    [Hauptplatine_v3.3dzo_logic_compact_routed_150x90.kicad_pcb]
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2026-09-28 PCB v3.3dzr: reset logic routing architecture with GND plane and structured local fanouts
    [Hauptplatine_v3.3dzr_logic_structured_150x90.kicad_pcb]
2026-09-28 PCB v3.3dzs: reset to compact placement with GND plane only
    [Hauptplatine_v3.3dzs_logic_structured_150x90.kicad_pcb]
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2026-09-29 PCB v3.3eai: restore local +5V distribution for D1 D2 U4 U5 J6 J7
    [Hauptplatine_v3.3eai_logic_repair_150x90.kicad_pcb]
2026-09-29 PCB v3.3eaj: restore +5V main trunk from PS1 to U1 relays J4 U2 and logic block
    [Hauptplatine_v3.3eaj_logic_repair_150x90.kicad_pcb]
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2026-09-29 PCB v3.3ean: restore missing TOP and BOT coil output routes
    [Hauptplatine_v3.3ean_logic_repair_150x90.kicad_pcb]
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2026-09-29 PCB v3.3eav: clean remaining routing conflicts and clearances
    [Hauptplatine_v3.3eav_logic_repair_150x90.kicad_pcb]
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2026-09-29 PCB v3.3eax: fix final GND thermal and redundant ESP32 vias
    [Hauptplatine_v3.3eax_logic_repair_150x90.kicad_pcb]
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2026-09-29 PCB v3.3eaz: snap remaining signal routes to exact pad coordinates
    [Hauptplatine_v3.3eaz_logic_repair_150x90.kicad_pcb]
2026-09-29 Document PCB v3.3eaz exact pad endpoint fixes
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2026-09-29 PCB v3.3ebc: increase top AC_L board-edge clearance
    [Hauptplatine_v3.3ebc_logic_repair_150x90.kicad_pcb]
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2026-09-29 Document 230V safety review and remaining clearance work
2026-09-29 PCB v3.3ebb2: adopt user-corrected UP_FEED and L_PSU_FUSED routing
    [Hauptplatine_v3.3ebb2_logic_repair_150x90.kicad_pcb]
2026-09-29 PCB v3.3ebc2: improve remaining mains clearances on corrected base
    [Hauptplatine_v3.3ebc2_logic_repair_150x90.kicad_pcb]
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2026-09-29 PCB v3.3ebe2: correct Mean Well IRM-20-5 footprint and polarity
    [Hauptplatine_v3.3ebe2_logic_repair_150x90.kicad_pcb]
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2026-09-29 PCB v3.3ebg2: correct Littelfuse 646 fuse-holder pitch to 22.7mm
    [Hauptplatine_v3.3ebg2_logic_repair_150x90.kicad_pcb]
2026-09-29 PCB v3.3ebh2: fix Finder relay layer joins and final mains clearances
    [Hauptplatine_v3.3ebh2_logic_repair_150x90.kicad_pcb]
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2026-09-29 PCB v3.3ebj2: correct ESP32-S3 DevKitC-1 J1 header pin offset
    [Hauptplatine_v3.3ebj2_logic_repair_150x90.kicad_pcb]
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2026-09-29 PCB v3.3ebj2: correct ESP32-S3 DevKitC-1 J1 power and GPIO assignments
    [Hauptplatine_v3.3ebj2_logic_repair_150x90.kicad_pcb]
2026-09-29 Document PCB v3.3ebj2 ESP32 header correction
2026-09-29 PCB v3.3ebk2: fix final DRC electrical issues from v3.3ebj2
    [Hauptplatine_v3.3ebk2_logic_repair_150x90.kicad_pcb]
2026-09-29 Document PCB v3.3ebk2 DRC electrical fixes
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2026-09-29 Document PCB v3.3ebm2 final dangling fix
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2026-09-29 PCB v3.3ebr2: apply project-local footprint library to clean USB-clearance layout
    [Hauptplatine_v3.3ebr2_library_clean_usb_clearance_150x90.kicad_pcb]
2026-09-29 PCB v3.3ebs2: correctly switch all footprints to project-local library
    [Hauptplatine_v3.3ebs2_library_clean_fixed_150x90.kicad_pcb]
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2026-10-01 fix: verify STM32G031 LQFP32 pin mapping
2026-10-01 fix: correct PB7 physical pin and verify I2S mapping
    [PINBELEGUNG_v1.0.csv]
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2026-10-01 fix: correct KiCad user drawing layer definition
    [Sensorplatine_v1.0_placement_50x50.kicad_pcb]
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2026-10-01 fix: remove unsupported comments from KiCad v1.2 PCB
    [Sensorplatine_v1.2_50x50.kicad_pcb]
2026-10-01 fix: add KiCad segment timestamps to v1.2 PCB
    [Sensorplatine_v1.2_50x50.kicad_pcb]
2026-10-01 fix: reorder KiCad board graphics before track section in v1.2
    [Sensorplatine_v1.2_50x50.kicad_pcb]
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
